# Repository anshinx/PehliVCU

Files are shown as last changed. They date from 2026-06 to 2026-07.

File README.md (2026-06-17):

# Pehlivan VCU (Vehicle Control Unit) - REVO.1 🏎️⚡

Trakya Üniversitesi Pehlivan Team ve Tas-Pro (Tasarım ve Proje Topluluğu) bünyesinde Shell Eco-marathon yarış aracı için özel olarak geliştirilmiş, endüstriyel standartlarda **Araç Kontrol Ünitesi (VCU)** donanım ve gömülü yazılım projesidir.

Bu kart; verimlilik, hafiflik ve kurşungeçirmez gürültü bağışıklığı (EMI/EMC) felsefesiyle, geleneksel ağır komponentlerin (lineer regülatörler, taş dirençler vb.) yerini tamamen akıllı yazılımsal ve anahtarlamalı çözümlere bırakması amacıyla sıfırdan tasarlanmıştır.

---

## 🛠️ Teknik Özellikler & Donanım Mimarisi

* **Ana İşlemci:** STM32G431 (ARM Cortex-M4 @170MHz, Matematik Hızlandırıcı CORDIC & FMAC).
* **Güç Girişi:** 12V - 14.4V Yarış Aküsü (Doğrudan besleme).
* **Periferi Beslemeleri:** * Yeni nesil yüksek verimli anahtarlamalı güç katı.
  * Nextion HMI, LoRa ve SD Kart modülleri için `100nF` seramik ve `10µF` kutuplu elektrolitik filtre kombinasyonlu izole besleme hatları.
* **Güç Çıkışları (Sürücü Katı):** `BTS432` Akıllı Güç Anahtarları (Far, Sinyal ve Fren Lambası kontrolü için).
* **Haberleşme & Telemetri:** * Doğrudan işlemciye bağlı LoRa Modülü (Kablosuz Telemetri).
  * Nextion HMI Ekran Arayüzü (UART).
  * FDCAN (Geriye dönük klasik CAN-Bus uyumlu, pitte maksimum esneklik).
* **Veri Günlüğü (Data Logging):** SD Kart Modülü üzerinden SPI haberleşmeli, anlık veri kaybını engelleyen "Kara Kutu" loglama altyapısı.
* **Zaman Senkronizasyonu:** CR2032/Düğme Pil destekli dahili RTC (Real Time Clock) mimarisi.

---

## ⚡ Donanım Tasarım Radikalleri (Neden REVO.1?)

REVO.1 revizyonu, pitteki kriz anlarını ve araç içi verimliliği maksimuma çıkarmak için şu kritik donanımsal kararlarla şekillendirilmiştir:

1. **Sıfır Taş Direnç / Sıfır Isı:** Şerit LED'lerin akım sınırlaması için kaba ve el yakan taş dirençler kullanılmamıştır. Akım kontrolü, STM32'nin Timer birimleri üzerinden **yazılımsal PWM (Sinyal Genişlik Modülasyonu)** ile çözülmüştür. Akü 14.4V'a vurduğunda lamba hatları `%83 Duty Cycle` ile kilitlenerek ortalama akım ideal 12V seviyesine çekilir.
2. **Yüksek Titreşim Dayanımı:** Kart üzerindeki 16 MHz harici kristal katında, yarış esnasındaki vibrasyondan bacakların yorulup kopmasını engellemek amacıyla bacaklı kılıflar yerine **Raltron 3225 4-SMD (RH100-16.000-18-2020-TR)** seramik kılıf tercih edilmiştir. Kristal yük kapasitesi ($C_L = 18\text{pF}$) hesaba katılarak hatlar `26pF` (veya `22pF`/`27pF`) kondansatörlerle stabilize edilmiştir.
3. **Parazit Bağışıklığı & Reset Koruması:** Araç içi motor sürücülerin ve yüksek akım hatlarının yaratacağı manyetik gürültülerden (EMI) korunmak için `NRST` (Reset) pini harici **10 kΩ dirençle `+3V3` hattına asılmış (Pull-Up)** ve `100nF` kondansatör ile şaseye filtrelenmiştir.
4. **Çift Katmanlı Bakır Havuzu:** Gürültü bağışıklığı için Bottom Layer tamamen kesintisiz `GND` bakır dolgusuyla kaplanmış, Top Layer ise STM32 etrafında `3V3` güç adalarıyla zırhlandırılmıştır.

---

## 🛰️ Gecikme (Latency) & Telemetri Lojiği

Kart üzerindeki pil destekli RTC donanımı, pit duvarı ile araç arasındaki LoRa veri transferinin gecikme süresini (latency) milisaniyelik çözünürlükle hesaplamak için kullanılır:
* Araç çalıştırılmadan önce bilgisayardan (veya Nextion üzerinden) Unix Epoch Time sinyaliyle RTC eşitlenir.
* VCU, LoRa paketini fırlatırken Unix zaman damgasının arkasına `HAL_GetTick()` değerinin son 3 basamağını ekler (`[UnixTimestamp].[Milisaniye]`).
* Pit tarafındaki alıcı yazılım, paketin varış zamanı ile paket içindeki zaman damgasını çıkararak hattaki milisaniyelik gecikmeyi anlık olarak raporlar.

---

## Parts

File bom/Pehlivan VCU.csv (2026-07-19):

Id | Designator | Footprint | Quantity | Designation | Supplier and ref
1 | C1 | C_Radial_D4.0mm_H7.0mm_P1.50mm | 1 | 100uF
2 | C2, C3, C6, C16 | C_Radial_D5.0mm_H5.0mm_P2.00mm | 4 | 10uF
3 | C4 | C_Radial_D5.0mm_H5.0mm_P2.00mm | 1 | 1uF
4 | C5, C15, C18, C19 | C_0805_2012Metric_Pad1.18x1.45mm_HandSolder | 4 | 100nF
5 | C7, C13 | C_1210_3225Metric_Pad1.33x2.70mm_HandSolder | 2 | 100nF
6 | C8 | C_0805_2012Metric_Pad1.18x1.45mm_HandSolder | 1 | 10uF
7 | C9, C10, C11, C14, C17 | C_0603_1608Metric | 5 | 100nF
8 | C12 | C_1210_3225Metric_Pad1.33x2.70mm_HandSolder | 1 | 10uF
9 | D1, D2, D9, D10 | LED_1206_3216Metric_Pad1.42x1.75mm_HandSolder | 4 | LED
10 | J1 | TerminalBlock_Phoenix_MKDS-1,5-2-5.08_1x02_P5.08mm_Horizontal | 1 | PWR_IN
11 | J2 | PinHeader_1x05_P2.54mm_Vertical | 1 | DEBUG
12 | J3 | TerminalBlock_Phoenix_MKDS-1,5-4-5.08_1x04_P5.08mm_Horizontal | 1 | Nextion
13 | J4 | TerminalBlock_Phoenix_MKDS-1,5-2-5.08_1x02_P5.08mm_Horizontal | 1 | CAN
14 | J5 | PinSocket_1x06_P2.54mm_Vertical | 1 | SD_CARD MODULE
15 | J6 | PinSocket_1x04_P2.54mm_Horizontal | 1 | LORA
16 | J7 | TerminalBlock_Phoenix_MKDS-1,5-3-5.08_1x03_P5.08mm_Horizontal | 1 | IN1
17 | J8 | TerminalBlock_Phoenix_MKDS-1,5-3-5.08_1x03_P5.08mm_Horizontal | 1 | IN2
18 | J9 | TerminalBlock_Phoenix_MKDS-1,5-3-5.08_1x03_P5.08mm_Horizontal | 1 | GND
19 | J10 | TerminalBlock_Phoenix_MKDS-1,5-3-5.08_1x03_P5.08mm_Horizontal | 1 | Headlights
20 | J11 | TerminalBlock_Phoenix_MKDS-1,5-3-5.08_1x03_P5.08mm_Horizontal | 1 | Blinker
21 | J12 | TerminalBlock_Phoenix_MKDS-1,5-2-5.08_1x02_P5.08mm_Horizontal | 1 | Stop
22 | Q4, Q5 | SOT-23 | 2 | BC817
23 | R1, R2, R16, R17 | R_0805_2012Metric | 4 | 1k
24 | R3, R6, R7, R8, R9 | R_0805_2012Metric | 5 | 10k
25 | R4 | R_0805_2012Metric | 1 | 100R
26 | R5 | R_0603_1608Metric_Pad0.98x0.95mm_HandSolder | 1 | 47R
27 | R10, R11, R13, R14, R15 | R_0805_2012Metric | 5 | 4k7
28 | R19, R20 | R_0805_2012Metric_Pad1.20x1.40mm_HandSolder | 2 | 4.7K
29 | TP1, TP2, TP3, TP4, TP5, TP6, TP7, TP8, TP9 | TestPoint_Pad_D1.0mm | 9 | TestPoint
30 | U1 | TO-220-3_Vertical | 1 | L7805
31 | U2 | SOT-223-3_TabPin2 | 1 | LM1117MP-3.3
32 | U3 | SOIC-8_3.9x4.9mm_P1.27mm | 1 | TJA1051T-3
33 | U5, U6, U7, U8, U9 | TO-263-4 | 5 | BTS432
34 | U10 | LQFP-48_7x7mm_P0.5mm | 1 | STM32G431C8Tx

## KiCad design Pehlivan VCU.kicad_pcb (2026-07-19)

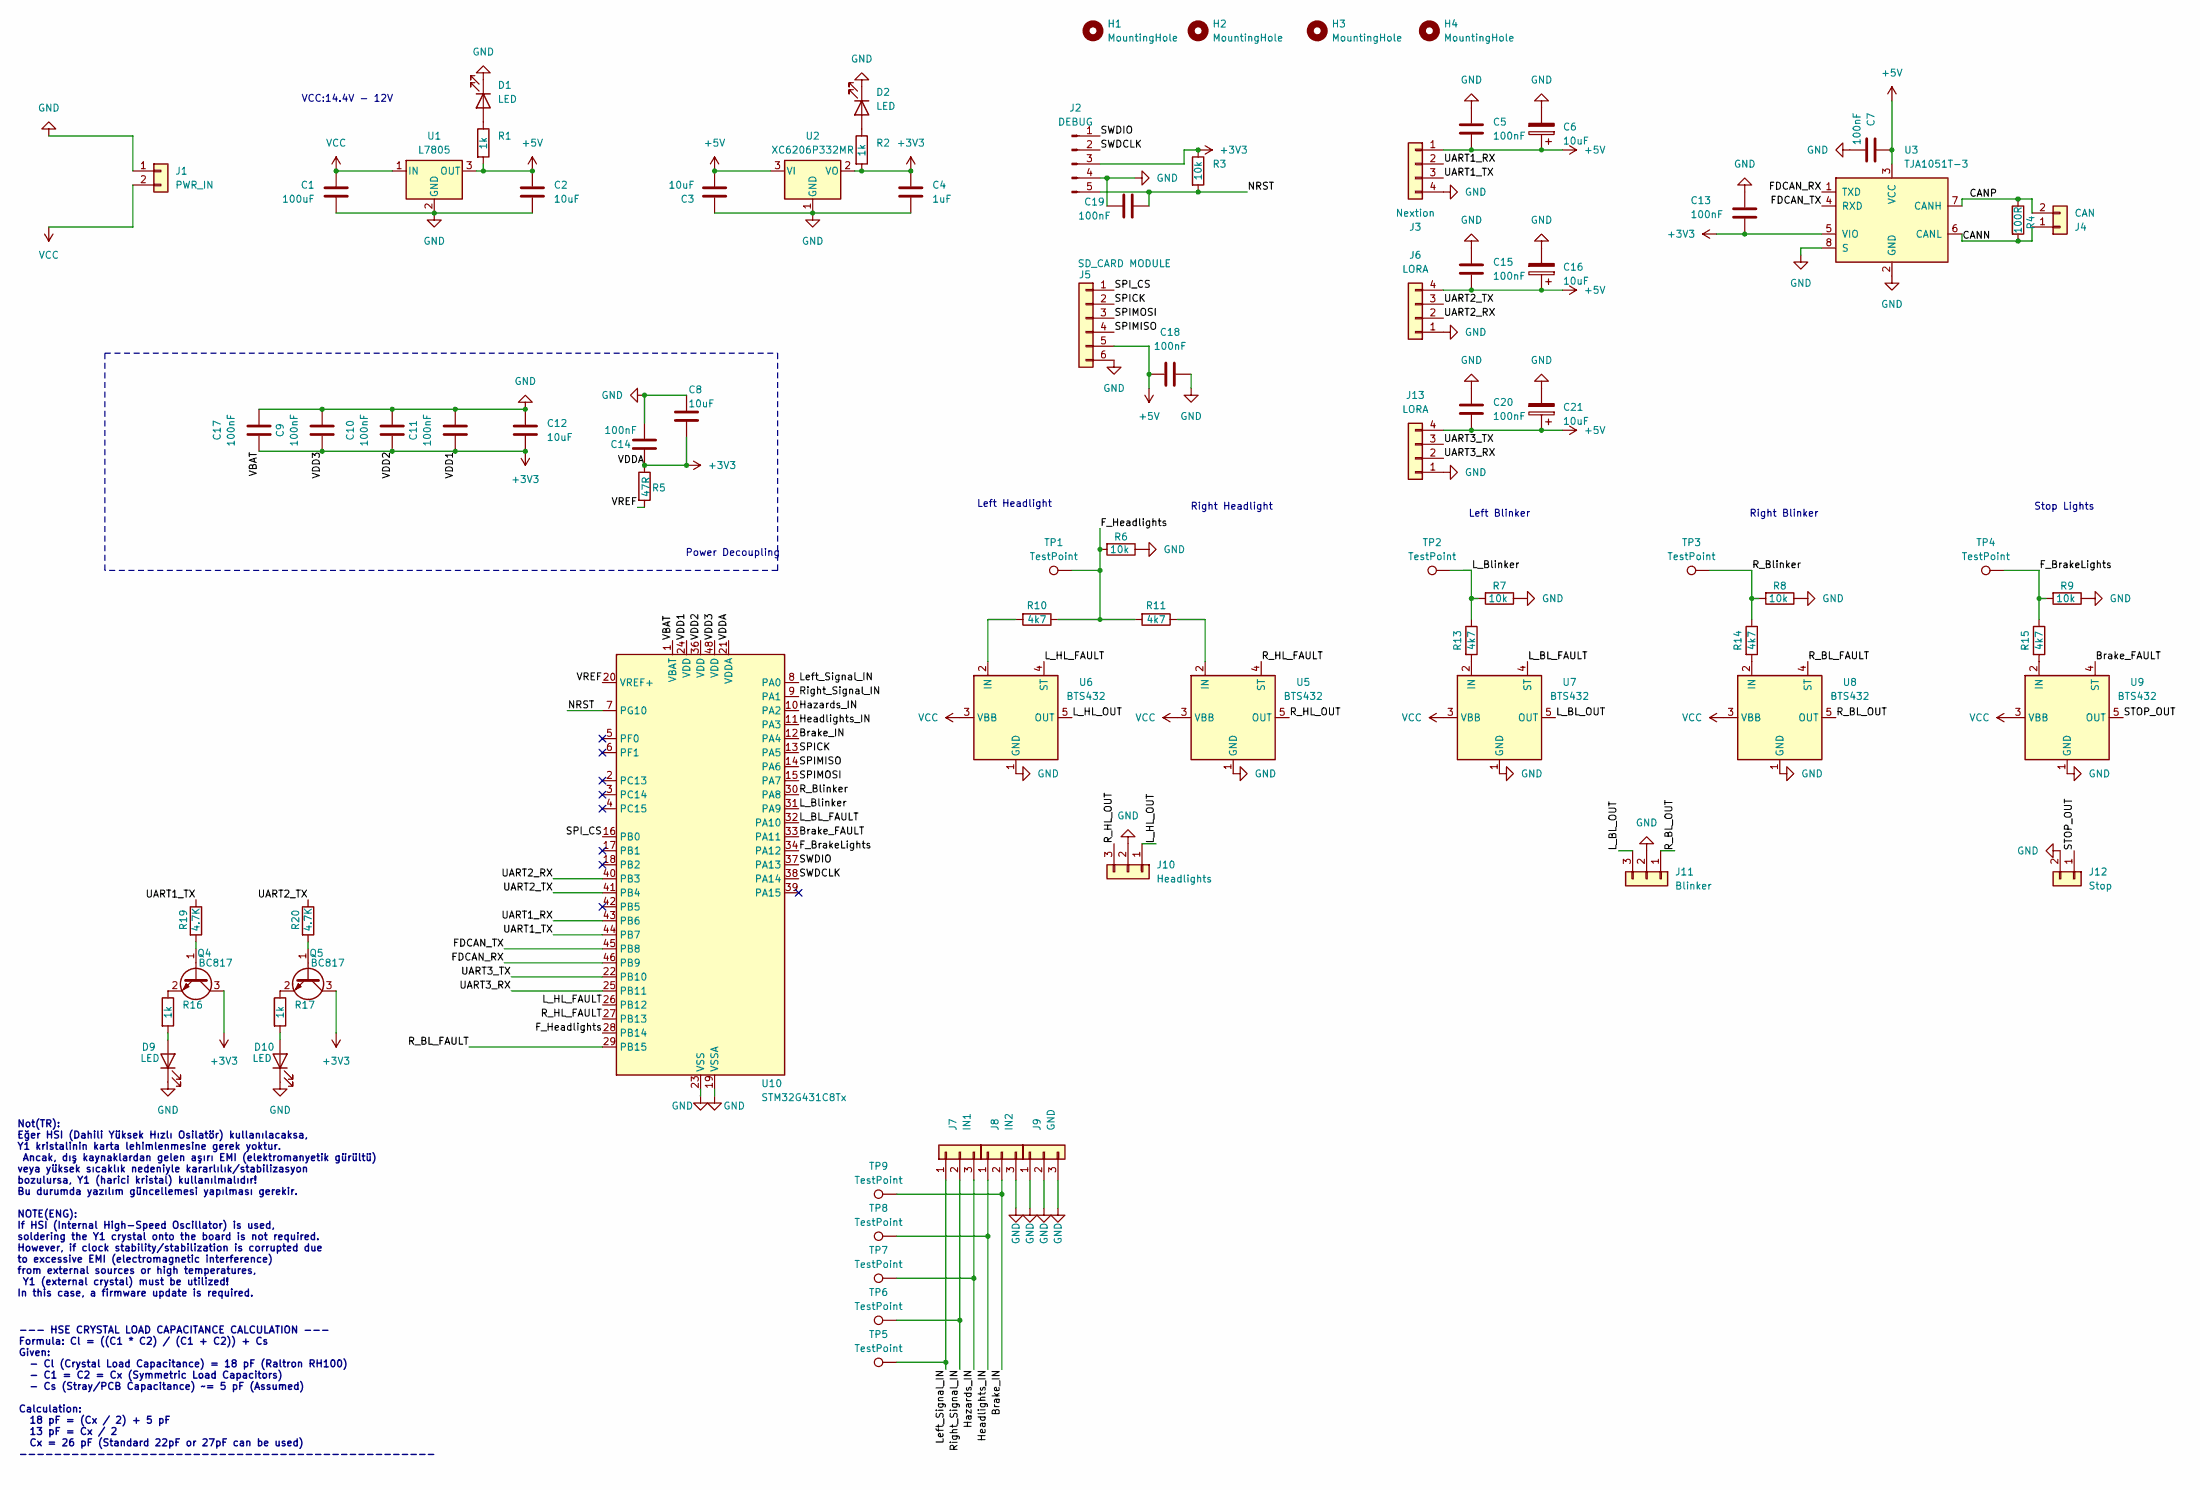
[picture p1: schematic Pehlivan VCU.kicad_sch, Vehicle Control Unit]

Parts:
C1: 100uF; C_Radial_D4.0mm_H7.0mm_P1.50mm
C2, C3, C6, C16, C21: 10uF; C_Radial_D5.0mm_H5.0mm_P2.00mm
C4: 1uF; C_Radial_D5.0mm_H5.0mm_P2.00mm
C5, C15, C18, C19, C20: 100nF; C_0805_2012Metric_Pad1.18x1.45mm_HandSolder
C7, C13: 100nF; C_1210_3225Metric_Pad1.33x2.70mm_HandSolder
C8: 10uF; C_0805_2012Metric_Pad1.18x1.45mm_HandSolder
C9, C10, C11, C14, C17: 100nF; C_0603_1608Metric
C12: 10uF; C_1210_3225Metric_Pad1.33x2.70mm_HandSolder
D1, D2, D9, D10: LED; LED_1206_3216Metric_Pad1.42x1.75mm_HandSolder
H1, H2, H3, H4: MountingHole; MountingHole_2.7mm_M2.5_DIN965_Pad
J1: PWR_IN; TerminalBlock_Phoenix_MKDS-1,5-2-5.08_1x02_P5.08mm_Horizont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
J2: DEBUG; PinHeader_1x05_P2.54mm_Vertical
J3: Nextion; TerminalBlock_Phoenix_MKDS-1,5-4-5.08_1x04_P5.08mm_Horizont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
J4: CAN; TerminalBlock_Phoenix_MKDS-1,5-2-5.08_1x02_P5.08mm_Horizont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
J5: SD_CARD MODULE; PinSocket_1x06_P2.54mm_Vertical
J6, J13: LORA; PinSocket_1x04_P2.54mm_Horizontal
J7: IN1; TerminalBlock_Phoenix_MKDS-1,5-3-5.08_1x03_P5.08mm_Horizont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
J8: IN2; TerminalBlock_Phoenix_MKDS-1,5-3-5.08_1x03_P5.08mm_Horizont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
J9: GND; TerminalBlock_Phoenix_MKDS-1,5-3-5.08_1x03_P5.08mm_Horizont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
J10: Headlights; TerminalBlock_Phoenix_MKDS-1,5-3-5.08_1x03_P5.08mm_Horizont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
J11: Blinker; TerminalBlock_Phoenix_MKDS-1,5-3-5.08_1x03_P5.08mm_Horizont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
J12: Stop; TerminalBlock_Phoenix_MKDS-1,5-2-5.08_1x02_P5.08mm_Horizont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
Q4, Q5: BC817; SOT-23
R1, R2, R16, R17: 1k; R_0805_2012Metric
R3, R6, R7, R8, R9: 10k; R_0805_2012Metric
R4: 100R; R_0805_2012Metric
R5: 47R; R_0603_1608Metric_Pad0.98x0.95mm_HandSolder
R10, R11, R13, R14, R15: 4k7; R_0805_2012Metric
R19, R20: 4.7K; R_0805_2012Metric_Pad1.20x1.40mm_HandSolder
TP1, TP2, TP3, TP4, TP5, TP6, TP7, TP8, TP9: TestPoint; TestPoint_Pad_D1.0mm
U1: L7805; TO-220-3_Vertical
U2: XC6206P332MR; SOT-23-3
U3: TJA1051T-3; SOIC-8_3.9x4.9mm_P1.27mm
U5, U6, U7, U8, U9: BTS432; TO-263-4
U10: STM32G431C8Tx; LQFP-48_7x7mm_P0.5mm

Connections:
+3V3: C4.1, C8.2, C9.1, C10.1, C11.1, C12.2, C13.2, C14.1, C17.1, J2.3, Q4.3 (C), Q5.3 (C), R2.2, R3.1, R5.1, U2.2 (VO), U3.5 (VIO), U10.1 (VBAT), U10.21 (VDDA), U10.24 (VDD), U10.36 (VDD), U10.48 (VDD)
+5V: C2.1, C3.1, C5.2, C6.1, C7.1, C15.2, C16.1, C18.2, C20.2, C21.1, J3.1, J5.5, J6.4, J13.4, R1.2, U1.3 (OUT), U2.3 (VI), U3.3 (VCC)
/Brake_FAULT: U9.4 (ST), U10.33 (PA11)
/Brake_IN: J8.2, TP9.1 (1_1), U10.12 (PA4)
/CANN: J4.1, R4.2, U3.6 (CANL)
/CANP: J4.2, R4.1, U3.7 (CANH)
/FDCAN_RX: U3.1 (TXD), U10.46 (PB9)
/FDCAN_TX: U3.4 (RXD), U10.45 (PB8)
/F_BrakeLights: R9.2, R15.1, TP4.1 (1_1), U10.34 (PA12)
/F_Headlights: R6.2, R10.1, R11.2, TP1.1 (1_1), U10.28 (PB14)
/Hazards_IN: J7.3, TP7.1 (1_1), U10.10 (PA2)
/Headlights_IN: J8.1, TP8.1 (1_1), U10.11 (PA3)
/L_BL_FAULT: U7.4 (ST), U10.32 (PA10)
/L_BL_OUT: J11.3, U7.5 (OUT)
/L_Blinker: R7.2, R13.1, TP2.1 (1_1), U10.31 (PA9)
/L_HL_FAULT: U6.4 (ST), U10.26 (PB12)
/L_HL_OUT: J10.1, U6.5 (OUT)
/Left_Signal_IN: J7.1, TP5.1 (1_1), U10.8 (PA0)
/NRST: C19.1, J2.5, R3.2, U10.7 (PG10)
/R_BL_FAULT: U8.4 (ST), U10.29 (PB15)
/R_BL_OUT: J11.1, U8.5 (OUT)
/R_Blinker: R8.2, R14.1, TP3.1 (1_1), U10.30 (PA8)
/R_HL_FAULT: U5.4 (ST), U10.27 (PB13)
/R_HL_OUT: J10.3, U5.5 (OUT)
/Right_Signal_IN: J7.2, TP6.1 (1_1), U10.9 (PA1)
/SPICK: J5.2, U10.13 (PA5)
/SPIMISO: J5.4, U10.14 (PA6)
/SPIMOSI: J5.3, U10.15 (PA7)
/SPI_CS: J5.1, U10.16 (PB0)
/STOP_OUT: J12.1, U9.5 (OUT)
/SWDCLK: J2.2, U10.38 (PA14)
/SWDIO: J2.1, U10.37 (PA13)
/UART1_RX: J3.2, U10.43 (PB6)
/UART1_TX: J3.3, R19.1, U10.44 (PB7)
/UART2_RX: J6.2, U10.40 (PB3)
/UART2_TX: J6.3, R20.1, U10.41 (PB4)
/UART3_RX: J13.2, U10.25 (PB11)
/UART3_TX: J13.3, U10.22 (PB10)
/VREF: R5.2, U10.20 (VREF+)
GND: C1.2, C2.2, C3.2, C4.2, C5.1, C6.2, C7.2, C8.1, C9.2, C10.2, C11.2, C12.1, C13.1, C14.2, C15.1, C16.2, C17.2, C18.1, C19.2, C20.1, C21.2, D1.1 (K), D2.1 (K), D9.1 (K), D10.1 (K), J1.1, J2.4, J3.4, J5.6, J6.1, J8.3, J9.1, J9.2, J9.3, J10.2, J11.2, J12.2, J13.1, R6.1, R7.1, R8.1, R9.1, U1.2 (GND), U2.1 (GND), U3.2 (GND), U3.8 (S), U5.1 (GND), U6.1 (GND), U7.1 (GND), U8.1 (GND), U9.1 (GND), U10.19 (VSSA), U10.23 (VSS), U10.35 (VSS), U10.47 (VSS)
unnamed: D1.2 (A), R1.1
unnamed: D2.2 (A), R2.1
unnamed: D9.2 (A), R16.2
unnamed: D10.2 (A), R17.2
unnamed: Q4.1 (B), R19.2
unnamed: Q4.2 (E), R16.1
unnamed: Q5.1 (B), R20.2
unnamed: Q5.2 (E), R17.1
unnamed: R11.1, U5.2 (IN)
unnamed: R10.2, U6.2 (IN)
unnamed: R13.2, U7.2 (IN)
unnamed: R14.2, U8.2 (IN)
unnamed: R15.2, U9.2 (IN)
VCC: C1.1, J1.2, U1.1 (IN), U5.3 (VBB), U6.3 (VBB), U7.3 (VBB), U8.3 (VBB), U9.3 (VBB)

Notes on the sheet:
Stop Lights
Right Headlight
Left Blinker
Right Blinker
--- HSE CRYSTAL LOAD CAPACITANCE CALCULATION --- Formula: Cl = ((C1 * C2) / (C1 + C2)) + Cs Given: - Cl (Crystal Load Capacitance) = 18 pF (Raltron RH100) - C1 = C2 = Cx (Symmetric Load Capacitors) - Cs (Stray/PCB Capacitance) ~= 5 pF (Assumed) Calculation: 18 pF = (Cx / 2) + 5 pF 13 pF = Cx / 2 Cx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
VCC:14.4V - 12V
Left Headlight
Not(TR): Eğer HSI (Dahili Yüksek Hızlı Osilatör) kullanılacaksa, Y1 kristalinin karta lehimlenmesine gerek yoktur. Ancak, dış kaynaklardan gelen aşırı EMI (elektromanyetik gürültü) veya yüksek sıcaklık nedeniyle kararlılık/stabilizasyon bozulursa, Y1 (harici kristal) kullanılmalıdır! Bu durumda yaz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
Power Decoupling

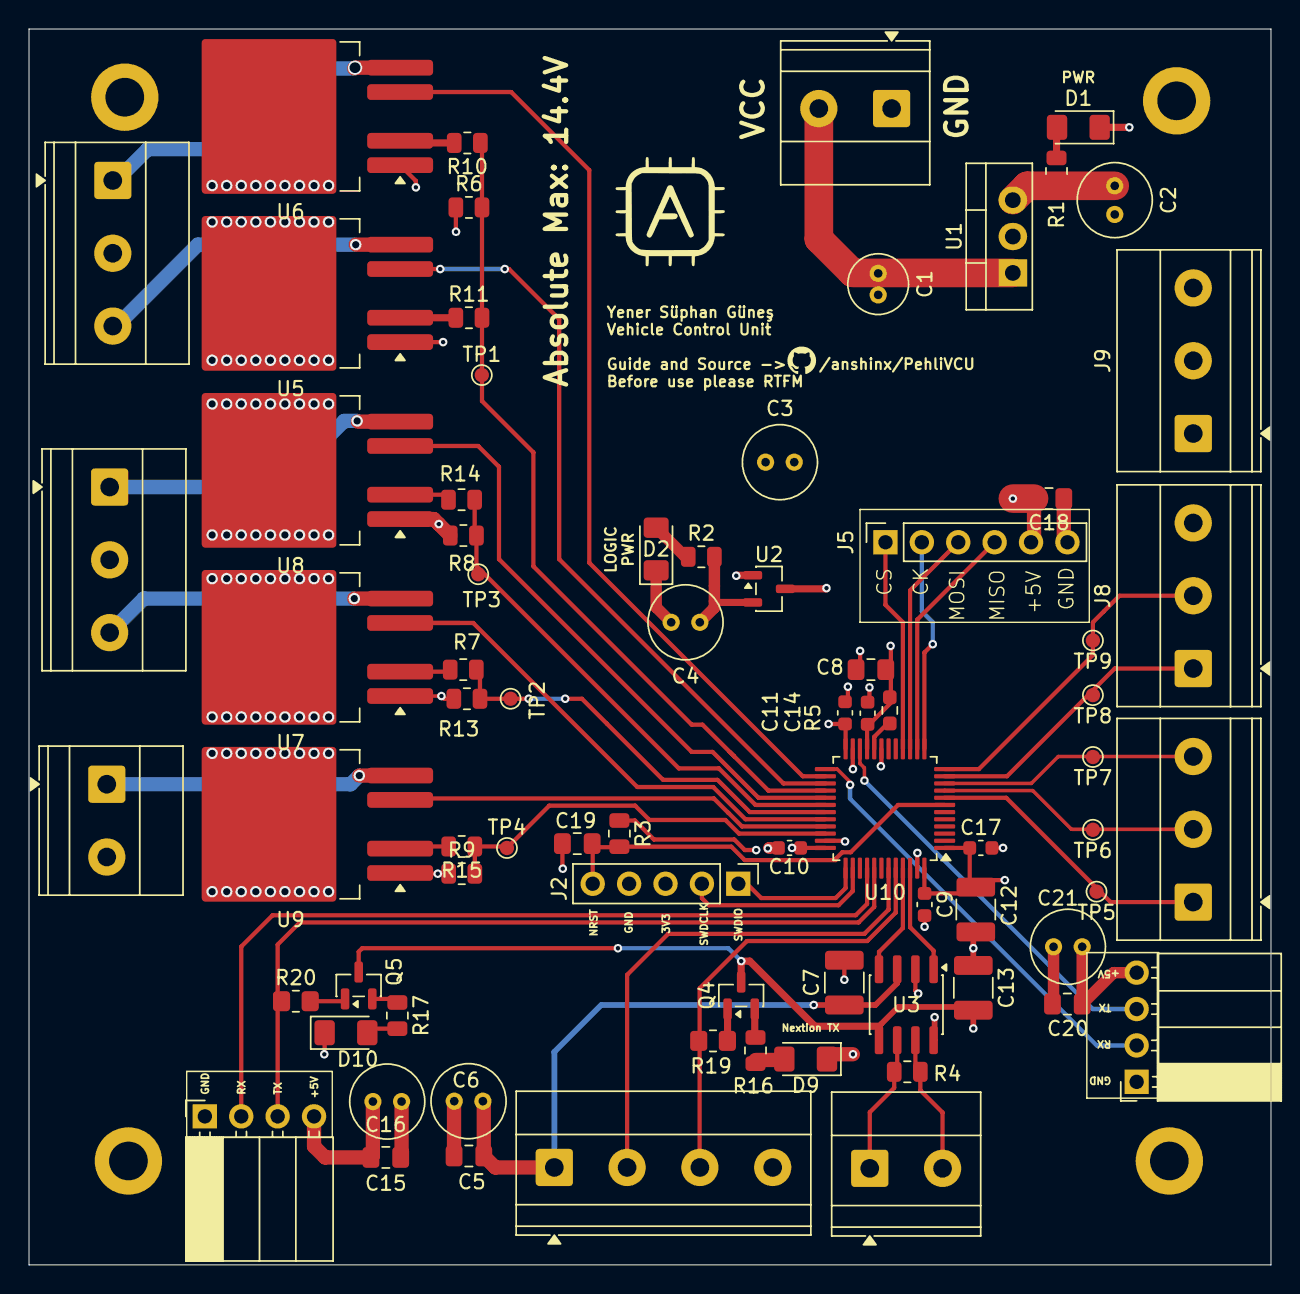
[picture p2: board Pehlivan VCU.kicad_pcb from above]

Board: 4 copper layers, 86.7 x 86.2 mm, 80 parts (0 on the bottom side), 54 nets.
